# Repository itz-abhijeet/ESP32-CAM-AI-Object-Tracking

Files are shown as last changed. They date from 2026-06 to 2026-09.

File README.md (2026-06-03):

# ESP32-CAM AI Object Tracking Camera

This project is a prototype AI object-tracking camera built with an ESP32-CAM, a second ESP32, a PCA9685 servo driver, two MG995/MG996-style servos, a custom YOLO model, and 3D-printed mechanical parts.

The ESP32-CAM streams live video to my laptop over Wi-Fi. Python runs a trained YOLO model to detect my custom 3D-printed target object. Then Python sends movement commands to a second ESP32, which controls the pan and tilt servos through the PCA9685 servo driver.

The goal of this project was to connect AI object detection with real hardware movement and design my own mechanical parts instead of using a ready-made pan-tilt mount.

## Demo

Project photo:

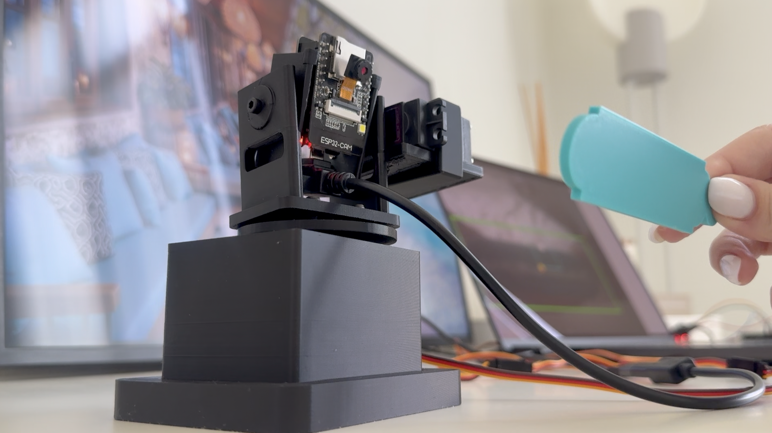
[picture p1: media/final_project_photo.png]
Final project photo


## How It Works

```text
ESP32-CAM
   ↓ Wi-Fi video stream
Laptop running Python + YOLO
   ↓ serial movement command
Second ESP32
   ↓ I2C
PCA9685 servo driver
   ↓
Pan and tilt servos
   ↓
Camera follows the object
```

## Hardware

* ESP32-CAM
* ESP32-WROOM-32 DevKit board
* PCA9685 16-channel servo driver
* 2 MG995/MG996-style servos
* External 5V power supply for the servos
* Jumper wires
* M3 screws
* Micro screws for the ESP32-CAM module
* 3D-printed camera mount parts

## Wiring

Basic wiring:

* ESP32 GPIO21 → PCA9685 SDA
* ESP32 GPIO22 → PCA9685 SCL
* ESP32 5V → PCA9685 VCC
* ESP32 GND → PCA9685 GND
* External 5V → PCA9685 V+
* External power GND → PCA9685 GND
* Pan servo → PCA9685 channel 0
* Tilt servo → PCA9685 channel 1

The PCA9685 uses I2C communication. SDA is the data line, and SCL is the clock line.

The servos are powered with external 5V power because servos need more current than the ESP32 should provide directly.

See wiring diagram:

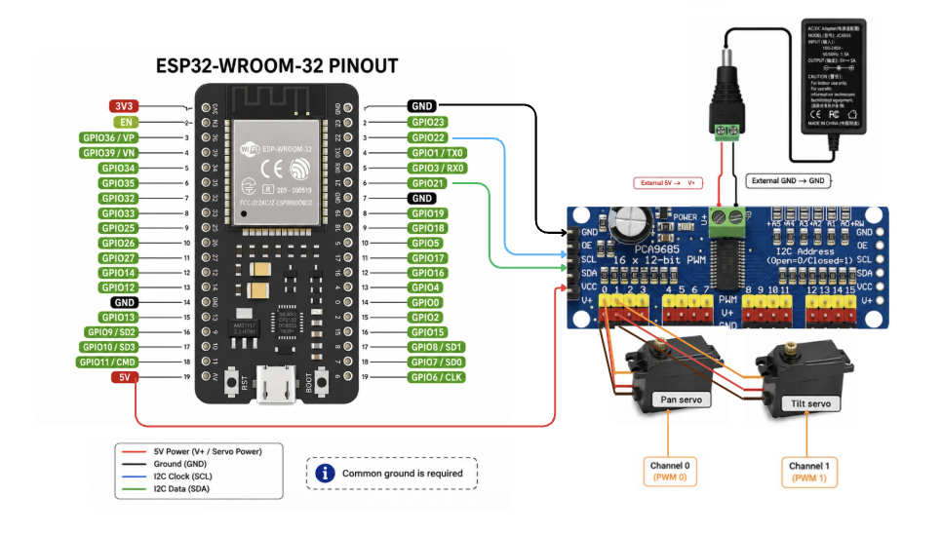
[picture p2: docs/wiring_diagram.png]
Wiring diagram


## 3D Printed Parts

The STL files are in the `stl/` folder.

The OpenSCAD source file is in the `openscad/` folder, so the design can be adjusted for different hardware.

This design was made for my specific prototype, so dimensions may need to be adjusted depending on your servo, camera board, screws, and printer tolerances.

## AI Model

I trained a custom YOLO model using my own images of a 3D-printed target object.

The trained model file is:

```text
models/best.pt
```

## Python Setup

Install the Python dependencies:

```bash
pip install -r requirements.txt
```

Update these values in `python/ai_tracking.py` for your own setup:

```python
MODEL_PATH = "../models/best.pt"
SERIAL_PORT = "YOUR_SERIAL_PORT"
CAMERA_URL = "http://YOUR_ESP32_CAM_IP:81/stream"
```

Run the main tracking script:

```bash
cd python
python3 ai_tracking.py
```

## Arduino Setup

Upload the ESP32-CAM streaming code to the ESP32-CAM:

```text
arduino/esp32_cam_stream/esp32_cam_stream.ino
```

Upload the servo controller code to the second ESP32:

```text
arduino/servo_controller/servo_controller.ino
```

Before uploading the ESP32-CAM code, replace the Wi-Fi placeholders with your own Wi-Fi name and password.

## Project Files

```text
python/
  capture_images.py
  prepare_dataset.py
  ai_tracking.py

arduino/
  esp32_cam_stream/
  servo_controller/

stl/
  3D-printable parts

openscad/
  editable OpenSCAD source

docs/
  wiring diagram and notes

models/
  trained YOLO model
```
## Testing

I also included a testing checklist for the full prototype behavior, including startup, tracking, lost-target behavior, servo movement, latency, edge limits, long-run stability, and thermal checks.

See: [Testing Checklist](docs/testing.md)

## Notes

This is still a prototype. The movement, wiring, 3D-printed parts, and code are still being improved.

For real-time tracking, a smaller and faster video stream worked better than a high-resolution stream with too much delay.

## License

This project is shared for learning and experimentation.

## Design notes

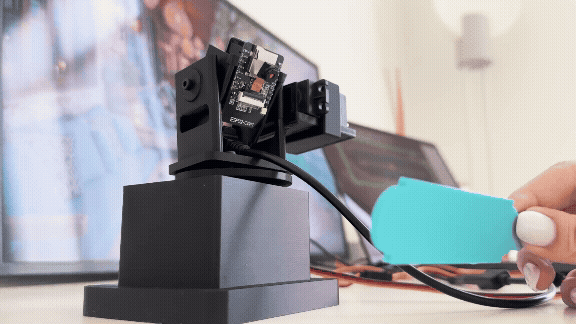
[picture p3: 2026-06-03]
media/demo.gif

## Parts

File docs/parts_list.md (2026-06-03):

# Setup Notes

- GPIO21 is used for SDA.
- GPIO22 is used for SCL.
- PCA9685 channel 0 controls the pan servo.
- PCA9685 channel 1 controls the tilt servo.
- Servos are powered with external 5V power.
- All grounds must be connected together.

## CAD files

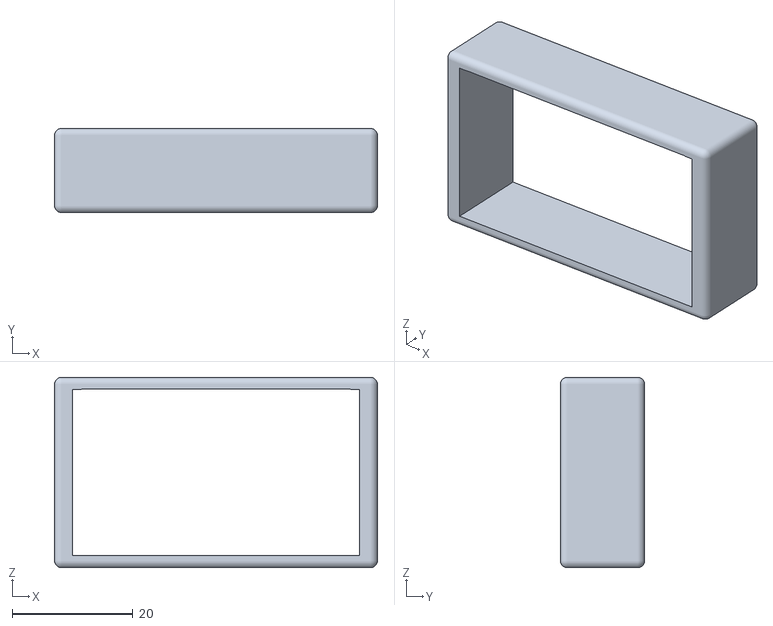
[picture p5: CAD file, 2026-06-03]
stl/servo_holder.stl
53.6 x 14.0 x 31.6

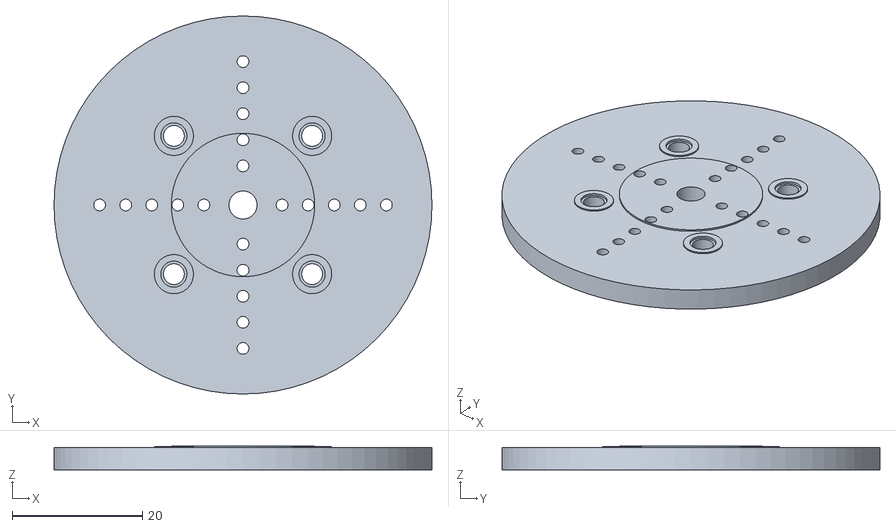
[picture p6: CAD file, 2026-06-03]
stl/horn.stl
58.0 x 58.0 x 3.65

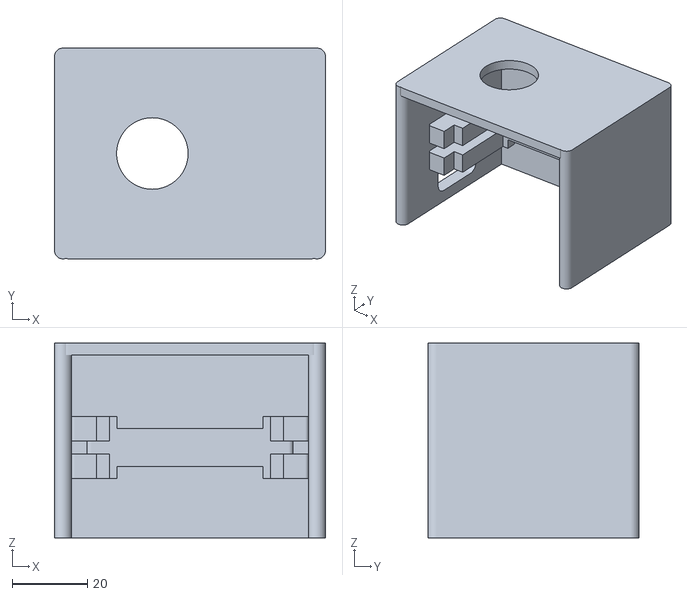
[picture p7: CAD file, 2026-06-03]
stl/pan_servo_cage.stl
72.0 x 56.0 x 51.7

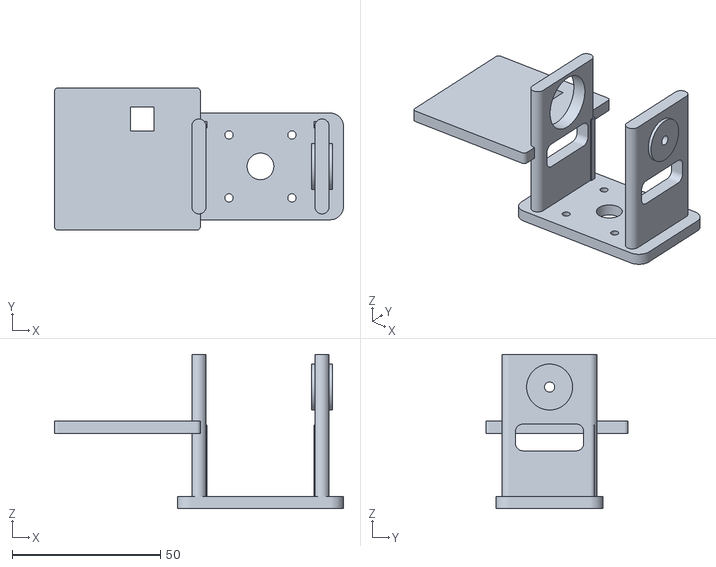
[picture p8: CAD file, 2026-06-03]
stl/tilt_yoke_base.stl
97.5 x 48.0 x 52.0

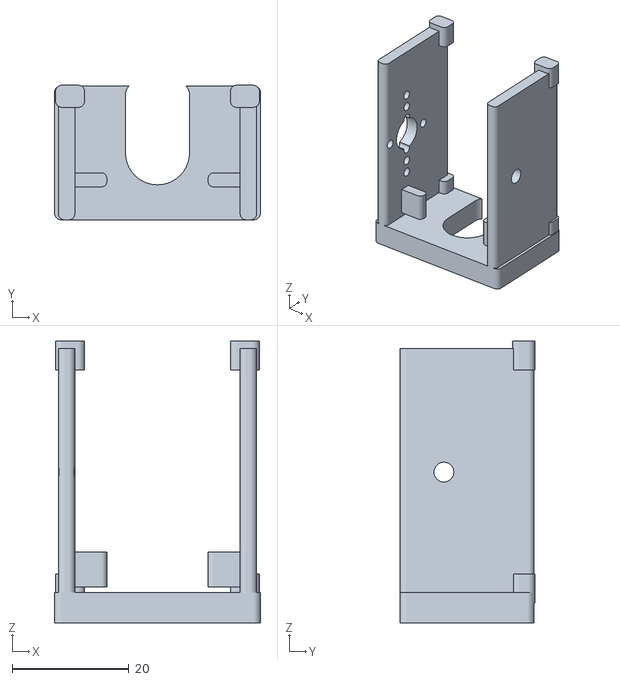
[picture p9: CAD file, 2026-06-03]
stl/camera_cradle.stl
35.4 x 23.1 x 48.4

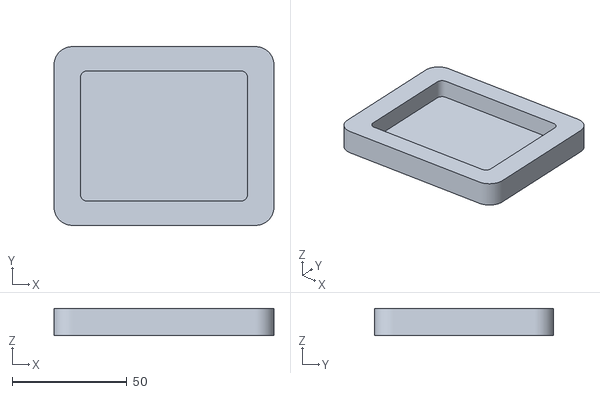
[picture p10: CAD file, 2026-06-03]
stl/base_plate.stl
96.0 x 78.0 x 12.0

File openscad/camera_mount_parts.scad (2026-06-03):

/*

  Main printable options:
    assembly
    base_plate
    pan_servo_cage
    pan_horn_disk
    tilt_yoke_base
    camera_cradle
    servo_holder
*/

$fn = 72;

PART = "assembly";

servo_holder_file = "../stl/servo_holder.stl";


m25_clear = 2.8;
m3_clear = 3.4;

cam_w = 27.0;
cam_h = 40.0;
cam_t = 19.0;

cam_clear_w = cam_w + 1.4;
cam_clear_h = cam_h + 1.4;
cam_clear_t = cam_t + 1.8;

base_plate_x = 96;
base_plate_y = 78;
base_plate_h = 4.0;
base_plate_r = 8.0;

cage_h = 39;
servo_center_z = 15.8;
ear_shelf_x = 9.5;
ear_shelf_y = 18.0;
ear_shelf_h = 3.2;

pan_disk_d = 43;
pan_disk_h = 5.0;
pan_screw_circle = 30;

yoke_base_h = 5;

yoke_inner_w = 36;
yoke_arm_t = 5.5;
yoke_arm_h = 49;
yoke_axis_z = 34;

left_arm_x = -(yoke_inner_w/2 + yoke_arm_t/2);
right_arm_x =  (yoke_inner_w/2 + yoke_arm_t/2);


cradle_w = cam_clear_w + 5.0;
cradle_t = cam_clear_t + 2.2;

module rounded_box(size=[10,10,10], r=2, center=false) {
    x=size[0]; y=size[1]; z=size[2];
    rr = min(r, min(x,y)/2 - 0.01);
    translate(center ? [-x/2,-y/2,-z/2] : [0,0,0])
        hull() {
            for (ix=[rr, x-rr])
                for (iy=[rr, y-rr])
                    translate([ix,iy,0]) cylinder(h=z, r=rr);
        }
}

module cyl_x(d,l) { rotate([0,90,0]) cylinder(d=d, h=l, center=true); }

module cyl_y(d,l) { rotate([90,0,0]) cylinder(d=d, h=l, center=true); }

module rounded_panel_y(w,h,depth,r) {
    union() {
        cube([max(0.01,w-2*r), depth, h], center=true);
        cube([w, depth, max(0.01,h-2*r)], center=true);
        for (sx=[-1,1])
            for (sz=[-1,1])
                translate([sx*(w/2-r),0,sz*(h/2-r)]) cyl_y(2*r, depth);
    }
}

module rounded_panel_x(w_y,h_z,depth_x,r) {
    union() {
        cube([depth_x, max(0.01,w_y-2*r), h_z], center=true);
        cube([depth_x, w_y, max(0.01,h_z-2*r)], center=true);
        for (sy=[-1,1])
            for (sz=[-1,1])
                translate([0,sy*(w_y/2-r),sz*(h_z/2-r)]) cyl_x(2*r, depth_x);
    }
}

module screw_circle_z(radius=15, d=2.8, h=8) {
    for (a=[45,135,225,315])
        rotate([0,0,a])
            translate([radius,0,0])
                cylinder(d=d, h=h, center=true);
}

module screw_square_x(y=10,z=10,d=2.4,depth=8) {
    for (sy=[-1,1])
        for (sz=[-1,1])
            translate([0, sy*y, sz*z]) cyl_x(d, depth);
}

module screw_square_y(x=16,z=22,d=2.4,depth=8) {
    for (sx=[-1,1])
        for (sz=[-1,1])
            translate([sx*x, 0, sz*z]) cyl_y(d, depth);
}

module bottom_base_plate_v1() {

    plate_h = 12.0;

    pan_cage_x = 72.0;
    pan_cage_y = 56.0;

    pan_cage_clearance = 0.9;

    pocket_x = pan_cage_x + pan_cage_clearance;
    pocket_y = pan_cage_y + pan_cage_clearance;

    pocket_depth = 9.0;

    bottom_floor = plate_h - pocket_depth;

    pocket_r = 3.0;

    pocket_shift_x = 0.0;
    pocket_shift_y = 0.0;

    plate_top_z = plate_h / 2;

    pocket_center_z = plate_top_z - pocket_depth / 2 + 0.01;

    difference() {
        rounded_box(
            [base_plate_x, base_plate_y, plate_h],
            r=base_plate_r,
            center=true
        );

        translate([
            pocket_shift_x,
            pocket_shift_y,
            pocket_center_z
        ])
            rounded_box(
                [pocket_x, pocket_y, pocket_depth + 0.08],
                r=pocket_r,
                center=true
            );
    }
}

module pan_servo_open_cage_v1() {

    mg_body_x = 40.0;
    mg_body_y = 20.0;
    mg_body_z = 40.5;

    mg_body_clear_x = mg_body_x + 2.8;
    mg_body_clear_y = mg_body_y + 2.6;
    mg_body_clear_z = mg_body_z + 2.5;

    mg_shaft_from_near_edge = 10;
    mg_boss_x_offset = -mg_body_x/2 + mg_shaft_from_near_edge;

    mg_boss_clear_d   = 19.0;
    mg_spline_clear_d = 10.5;

    mg_side_wall = 4.5;
    mg_back_wall = 4.5;
    mg_roof_h = 3.2;

    mg_bottom_gap = 2.5;

    mg_top_air_gap = 3.0;

    mg_servo_center_z = mg_bottom_gap + mg_body_clear_z/2;

    mg_cage_x = 72.0;
    mg_cage_y = 56.0;
    mg_cage_h = mg_bottom_gap + mg_body_clear_z + mg_top_air_gap + mg_roof_h;

    mg_mount_x = 29.0;
    mg_mount_y = 21.0;
    mg_mount_hole_d = 3.4;

    front_open_y = mg_cage_y/2 + 8.0;

    left_inner_x  = -mg_cage_x/2 + mg_side_wall;
    right_inner_x =  mg_cage_x/2 - mg_side_wall;

    wire_side = -1;

    wire_exit_y = 0.0;
    wire_exit_z = 10.0;
    wire_exit_w = 20.0;
    wire_exit_h = 12.0;

    body_half_x = mg_body_clear_x/2;
    guide_protrude = (mg_cage_x/2 - mg_side_wall) - body_half_x + 2.0;
    guide_y = mg_body_clear_y + 8.0;
    guide_h = 6.5;

    guide_z_low  = mg_servo_center_z - 5.0;
    guide_z_high = mg_servo_center_z + 5;

    rear_stop_inner_y = mg_body_clear_y/2;
    rear_stop_outer_y = mg_cage_y/2 - mg_back_wall;
    rear_stop_y_len = rear_stop_outer_y - rear_stop_inner_y;
    rear_stop_y_center = rear_stop_inner_y + rear_stop_y_len/2;
    rear_stop_h = 10.0;

    difference() {
        union() {
            translate([-mg_cage_x/2 + mg_side_wall/2, 0, mg_cage_h/2])
                rounded_box(
                    [mg_side_wall, mg_cage_y, mg_cage_h],
                    r=3,
                    center=true
                );

            translate([mg_cage_x/2 - mg_side_wall/2, 0, mg_cage_h/2])
                rounded_box(
                    [mg_side_wall, mg_cage_y, mg_cage_h],
                    r=3,
                    center=true
                );

            translate([0, mg_cage_y/2 - mg_back_wall/2, mg_cage_h/2])
                rounded_box(
                    [mg_cage_x, mg_back_wall, mg_cage_h],
                    r=3,
                    center=true
                );

            translate([0, 0, mg_cage_h - mg_roof_h/2])
                rounded_box(
                    [mg_cage_x, mg_cage_y, mg_roof_h],
                    r=4,
                    center=true
                );

            for (sx=[-1,1])
                for (gz=[guide_z_low, guide_z_high])
                    translate([
                        sx * (mg_cage_x/2 - mg_side_wall - guide_protrude/2),
                        0,
                        gz
                    ])
                        rounded_box(
                            [guide_protrude, guide_y, guide_h],
                            r=0.9,
                            center=true
                        );

            translate([0, rear_stop_y_center, mg_servo_center_z])
                rounded_box(
                    [mg_body_clear_x + 12.0, rear_stop_y_len, rear_stop_h],
                    r=1.2,
                    center=true
                );
        }

        translate([0, 0, mg_servo_center_z])
            cube(
                [mg_body_clear_x, mg_body_clear_y, mg_body_clear_z],
                center=true
            );

        translate([0, -mg_cage_y/2, mg_servo_center_z])
            cube(
                [mg_body_clear_x + 7.0, front_open_y, mg_body_clear_z + 4.0],
                center=true
            );

        translate([mg_boss_x_offset, 0, mg_cage_h - mg_roof_h/2])
            cylinder(
                d=mg_boss_clear_d,
                h=mg_roof_h + 5.0,
                center=true
            );

        translate([mg_boss_x_offset, 0, mg_cage_h])
            cylinder(
                d=mg_spline_clear_d,
                h=16.0,
                center=true
            );

        for (sx=[-1,1])
            for (sy=[-1,1])
                translate([sx*mg_mount_x, sy*mg_mount_y, 3])
                    cylinder(
                        d=mg_mount_hole_d,
                        h=14,
                        center=true
                    );

        translate([
            wire_side * mg_cage_x/2,
            wire_exit_y,
            wire_exit_z
        ])
            rounded_panel_x(
                wire_exit_w,
                wire_exit_h,
                mg_side_wall + 10,
                3
            );
    }
}

module pan_horn_adapter_disk_v1() {

    local_eps = 0.02;

    disk_h = 3.4;

    adapter_disk_d = max(pan_disk_d, 58.0);

    mg_horn_recess_depth = 1.0;

    mg_horn_center_d = 21.5;

    mg_horn_arm_w = 7.8;
    mg_horn_arm_len = 44.0;

    mg_center_access_d = 4.3;

    mg_horn_hole_d_horizontal = 1.8;
    mg_horn_hole_d_vertical   = 1.8;

    mg_horn_hole_positions = [6, 10, 14, 18, 22];

    outer_screw_d = 3.2;

    neck_counterbore_d = 4.0;
    neck_counterbore_depth = 0.35;

    difference() {
        union() {
            cylinder(
                d=adapter_disk_d,
                h=disk_h,
                center=true
            );

            translate([0, 0, disk_h/2])
                cylinder(
                    d=22.0,
                    h=0.5,
                    center=true
                );
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

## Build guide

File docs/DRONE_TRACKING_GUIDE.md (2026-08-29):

# Optical Drone Detection & Tracking Setup Guide

This guide explains how to connect and configure this project hardware and software specifically for optical drone (UAV) detection and tracking using computer vision and standard pan-tilt mounts.

---

## 1. System Architecture

```text
[ ESP32-CAM ] 
      │ (Wi-Fi MJPEG Stream)
      ▼
[ Laptop / PC ] ── (Runs YOLO Detection + PID Tracking)
      │ (USB Serial: Movement Commands)
      ▼
[ ESP32 Controller ] 
      │ (I2C)
      ▼
[ PCA9685 Driver ] ── (PWM) ──> [ Pan / Tilt Servos ]
```

---

## 2. Hardware Connections

### Wiring Diagram

1. **Second ESP32 to PCA9685 Driver (I2C Control):**
   * `ESP32 GPIO 21 (SDA)` → `PCA9685 SDA`
   * `ESP32 GPIO 22 (SCL)` → `PCA9685 SCL`
   * `ESP32 5V / VIN` → `PCA9685 VCC` (Logic Power)
   * `ESP32 GND` → `PCA9685 GND`

2. **PCA9685 to Servos & External Power:**
   * **Pan Servo:** Plug into **Channel 0** on the PCA9685.
   * **Tilt Servo:** Plug into **Channel 1** on the PCA9685.
   * **External 5V Power Supply:** Connect to the `V+` and `GND` screw terminals on the PCA9685.

> **Important:** Always connect the ground (`GND`) of the external power supply and the ESP32 together to maintain a common ground reference. Never draw servo operating current directly from the ESP32 board pins.

---

## 3. Firmware Flashing

### A. ESP32-CAM (Video Streaming)
1. Open `arduino/esp32_cam_stream/esp32_cam_stream.ino` in the Arduino IDE.
2. Update your local Wi-Fi details:
   ```cpp
   const char* ssid = "YOUR_WIFI_SSID";
   const char* password = "YOUR_WIFI_PASSWORD";
   ```
3. Set the board to **AI Thinker ESP32-CAM** and upload.
4. Open the Serial Monitor (115200 baud) to obtain the device's IP address (e.g., `http://192.168.1.50:81/stream`).

### B. Second ESP32 (Pan/Tilt Motion Controller)
1. Open `arduino/servo_controller/servo_controller.ino` in the Arduino IDE.
2. Select your board (e.g., **ESP32 Dev Module**) and target COM port.
3. Upload the firmware. Leave the ESP32 connected to the PC via USB.

---

## 4. Software Configuration for Drone Detection

### Model Selection
Standard YOLO models (such as YOLOv8) can detect commercial drones or aerial objects using custom datasets or classes such as `airplane` or custom-trained drone weights (`.pt`).

### Updating `python/ai_tracking.py`
Edit the configuration variables in `python/ai_tracking.py`:

```python
# Path to your YOLO model trained on drone imagery
MODEL_PATH = "yolov8n.pt"  # Or your custom drone detection model: "models/drone_model.pt"

# Serial port connected to the Second ESP32
SERIAL_PORT = "COM3"  # Adjust based on your Device Manager / COM port

# ESP32-CAM stream URL obtained from Serial Monitor
CAMERA_URL = "http://192.168.1.50:81/stream"
```

---

## 5. Running the Tracker

1. Power on the servos and ESP32-CAM.
2. Run the main tracking script:
   ```bash
   cd python
   python ai_tracking.py
   ```
3. The optical tracker will stream the video feed, detect the aerial target, compute position offsets from the frame center, and send real-time pan/tilt correction commands to maintain visual lock.

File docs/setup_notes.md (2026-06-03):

# Parts List

- ESP32-CAM
- ESP32-WROOM-32 DevKit board
- PCA9685 16-channel servo driver
- 2 servos
- External 5V power supply
- Jumper wires
- M3 screws
- Micro screws for ESP32-CAM module
- 3D-printed parts

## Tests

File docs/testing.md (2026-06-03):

# Testing Checklist

This checklist was used to test the ESP32-CAM AI object-tracking prototype as a full system.

The full system flow is:

```text
ESP32-CAM video stream
→ Python + YOLO detection
→ object center calculation
→ serial movement command
→ second ESP32
→ PCA9685 servo driver
→ pan/tilt servo movement
→ camera follows the target
```

This project is still a prototype, so the checklist focuses on behavior, stability, safety, and repeatability.

---

## 1. Startup Test

**Goal:** Make sure the system starts cleanly.

**Steps:**

1. Power the ESP32-CAM.
2. Power the second ESP32 and servo driver.
3. Start the Python tracking script.
4. Check the terminal, OpenCV window, and physical camera movement.

**Expected result:**

* YOLO model loads successfully.
* Serial port opens.
* ESP32-CAM stream opens.
* OpenCV window appears.
* Camera receives the center command.
* Servos move to the center position smoothly.
* No sudden movement or servo buzzing.

---

## 2. Center Command Test

**Goal:** Make sure the `C` command centers the camera correctly.

**Steps:**

1. Start tracking.
2. Let the camera follow the target.
3. Press `c` in the OpenCV window.

**Expected result:**

* Camera returns to center smoothly.
* Old movement commands are cleared.
* Tracking resumes normally after centering.
* Camera does not jump back to an old target position.

---

## 3. Quit Behavior Test

**Goal:** Make sure the program exits cleanly.

**Steps:**

1. Start tracking.
2. Let the camera move.
3. Press `q`.

**Expected result:**

* Camera sends a center command before exit.
* OpenCV window closes.
* Serial port closes.
* Python process exits.
* The next launch works without a “port busy” error.

---

## 4. No Target Test

**Goal:** Make sure the camera stays stable when the target is not visible.

**Steps:**

1. Remove the target object from the camera view.
2. Watch the OpenCV window and physical camera.

**Expected result:**

* Camera stops moving.
* No random searching behavior.
* No tracking of the background.
* OpenCV window shows “No target detected.”
* Terminal shows “No target.”

---

## 5. Lost Target While Moving Test

**Goal:** Make sure the camera stops when the target disappears during movement.

**Steps:**

1. Put the target object on one side of the frame.
2. Let the camera begin moving toward it.
3. Quickly remove the object from the frame.

**Expected result:**

* Camera stops shortly after the target disappears.
* Camera does not continue moving toward the old target position.
* No delayed movement or runaway behavior.

---

## 6. Target Reacquisition Test

**Goal:** Make sure tracking restarts correctly when the object returns.

**Steps:**

1. Remove the target for 2–3 seconds.
2. Put the target back into the frame.

**Expected result:**

* System may briefly show `LOCKING`.
* Tracking resumes after stable detection.
* Camera does not jump suddenly to an old position.
* Camera follows the target again normally.

---

## 7. Pan Direction Test

**Goal:** Verify left/right movement direction.

**Steps:**

1. Put the target near the center.
2. Move the target slowly to the right.
3. Move the target slowly to the left.

**Expected result:**

* Target moves right → camera pans right.
* Target moves left → camera pans left.
* Camera moves toward the target, not away from it.

---

## 8. Tilt Direction Test

**Goal:** Verify up/down movement direction.

**Steps:**

1. Put the target near the center.
2. Move the target upward.
3. Move the target downward.

**Expected result:**

* Target moves up → camera tilts up.
* Target moves down → camera tilts down.
* Tilt axis does not move in the opposite direction.

---

## 9. Hold Zone Test

**Goal:** Make sure the camera does not twitch when the object is already near the center.

**Steps:**

1. Put the object close to the center of the frame.
2. Move it slightly inside the hold-zone rectangle.

**Expected result:**

* Camera stays still.
* Status shows `HOLD`.
* Movement commands stay near `D=(0,0)`.
* No small left/right or up/down twitching.

---

## 10. Smooth Tracking Test

**Goal:** Check normal smooth tracking behavior.

**Steps:**

1. Move the target slowly from left to right.
2. Move it from right to left.
3. Move it up and down.

**Expected result:**

* Camera follows smoothly.
* Movement does not look shaky.
* Object stays near the center.
* No repeated stop-go-stop-go behavior.

---

## 11. Fast Movement Test

**Goal:** Check how the system reacts when the object moves quickly.

**Steps:**

1. Start with the target in the center.
2. Move it quickly to the side.
3. Move it quickly up or down.

**Expected result:**

* Camera reacts without going out of control.
* Camera does not overshoot too much.
* Movement settles after the object stops.
* No continuous oscillation.

---

## 12. False Positive Test

**Goal:** Make sure the camera does not follow random objects.

**Steps:**

1. Remove the target object.
2. Place similar-looking objects or hands in the frame.
3. Change the background or lighting.

**Expected result:**

* YOLO does not confidently track the wrong object.
* Camera does not aggressively follow the background.
* If false detections happen, they should be limited and not cause unstable movement.

---

## 13. Latency Test

**Goal:** Check if the camera is reacting to recent frames instead of old buffered frames.

**Steps:**

1. Move the target quickly in front of the camera.
2. Watch the OpenCV window.
3. Watch the physical servo response.

**Expected result:**

* OpenCV window shows the recent target position.
* Camera does not follow where the target was one second ago.
* Tracking delay is acceptable for a prototype.

---

## 14. Edge Limit Test

**Goal:** Make sure servos stay within safe physical limits.

**Steps:**

1. Move the target far left and far right.
2. Move the target high and low.
3. Watch the servo and 3D-printed parts.

**Expected result:**

* Camera does not hit the plastic frame.
* Servo horn does not push against the mount.
* Camera cable does not get pulled.
* No buzzing at servo limits.

---

## 15. Arduino Timeout Test

**Goal:** Make sure the servo controller stops safely if Python stops sending commands.

**Steps:**

1. Start tracking.
2. Let the camera move.
3. Stop or crash the Python script.

**Expected result:**

* Arduino stops updating movement after command timeout.
* Camera does not keep moving forever.
* Servo controller does not freeze.
* System can be restarted normally.

---

## 16. Command Protocol Test

**Goal:** Verify Python-to-Arduino serial commands.

**Command format:**

```text
C
D,panDelta,tiltDelta
```

**Expected result:**

* `C` centers the camera.
* `D,x,y` moves pan and tilt.
* `D,0,0` stops movement.
* Commands do not look chaotic when the target is near the center.

---

## 17. Long Run Test

**Goal:** Check stability over time.

**Steps:**

1. Run the project for 15–30 minutes.
2. Move the target occasionally.
3. Remove and return the target.
4. Press `c` occasionally to center.

**Expected result:**

* Python does not crash.
* Camera stream does not freeze.
* Serial connection stays active.
* Servos do not overheat.
* Tracking behavior stays consistent.

---

## 18. Thermal Test

**Goal:** Check if the electronics and servos stay within a safe temperature range.

**Steps:**
After a longer run, check:

* ESP32-CAM
* second ESP32
* PCA9685
* pan servo
* tilt servo

**Expected result:**

* Warm is expected.
* Very hot or too hot to touch is not good.
* If a servo is very hot, check mechanical friction, servo limits, weight balance, and power supply.

---

## 19. Repeatability Test

**Goal:** Make sure the project works consistently across multiple launches.

**Steps:**
Repeat 5 times:

1. Start Python.
2. Center the camera.
3. Track left/right.
4. Track up/down.
5. Remove target.
6. Return target.
7. Press `c`.
8. Press `q`.

**Expected result:**

* Behavior is consistent across launches.
* Serial port is released correctly.
* Camera centers correctly every time.
* Tracking does not become worse after restart.

---

## 20. Demo Quality Test

**Goal:** Check if the project is understandable in a short demo video.

**Expected result:**

* Within the first few seconds, it is clear that the camera follows the object.
* Movement looks smooth enough for a prototype.
* The object is visible.
* The camera does not look confused.
* The wiring and mechanical parts look intentional.
* The demo can be understood without a long explanation.

---

## Notes

This is a working prototype, not a commercial product. The tracking quality depends on:

* lighting
* ESP32-CAM stream quality
* camera latency
* servo power
* mechanical alignment
* target visibility
* YOLO model quality
* tuning values in the Python and Arduino code

Some values may need to be adjusted for different hardware or 3D-printed parts.

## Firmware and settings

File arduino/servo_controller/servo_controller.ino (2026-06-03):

#include <Wire.h>
#include <math.h>

#define PCA9685_ADDR 0x40

#define PAN_CH 0
#define TILT_CH 1

/*
  Servo controller for ESP32-CAM AI object tracking project

  Hardware:
  - Second ESP32-WROOM-32 DevKit
  - PCA9685 servo driver
  - Pan servo on PCA9685 channel 0
  - Tilt servo on PCA9685 channel 1
  - I2C: GPIO21 = SDA, GPIO22 = SCL

  Commands from Python:
  - C = center servos
  - D,panDelta,tiltDelta = move pan/tilt servos
*/

// SERVO CENTER

int panCenter = 300;
int tiltCenter = 410;

float panPos = panCenter;
float tiltPos = tiltCenter;

float targetPan = panCenter;
float targetTilt = tiltCenter;


// CENTER ANIMATION STATE

bool centeringMode = false;

float centerStartPan = 0;
float centerStartTilt = 0;

unsigned long centerStartTime = 0;

// Higher = slower
unsigned long centerDurationMs = 1150;

int centerWriteDeadband = 1;

// SERVO LIMITS

// PAN = left/right
int panMin = 180;
int panMax = 430;

// TILT = up/down
int tiltMin = 230;
int tiltMax = 470;

int PAN_DIR = 1;
int TILT_DIR = 1;

// TRACKING SETTINGS

unsigned long servoUpdateMs = 6;
unsigned long lastServoUpdate = 0;

int panMaxTargetLead = 45;
int tiltMaxTargetLead = 40;

unsigned long commandTimeoutMs = 500;
unsigned long lastCommandTime = 0;

float arriveThreshold = 2;

// PAN tuning
float panMinStep = 0.8;
float panMaxStep = 6.2;
float panGain = 0.15;

// TILT tuning
float tiltMinStep = 0.5;
float tiltMaxStep = 4.0;
float tiltGain = 0.09;

int tinyPanDeltaIgnore = 1;
int tinyTiltDeltaIgnore = 0;

int panWriteDeadband = 2;
int tiltWriteDeadband = 2;

int lastPanPWM = -9999;
int lastTiltPWM = -9999;

// SERIAL LINE BUFFER

char serialBuffer[48];
int serialIndex = 0;

// PCA9685 LOW LEVEL FUNCTIONS

void writeRegister(byte reg, byte value) {
  Wire.beginTransmission(PCA9685_ADDR);
  Wire.write(reg);
  Wire.write(value);
  Wire.endTransmission();
}

void setPWM(byte channel, int on, int off) {
  Wire.beginTransmission(PCA9685_ADDR);
  Wire.write(0x06 + 4 * channel);

  Wire.write(on & 0xFF);
  Wire.write(on >> 8);

  Wire.write(off & 0xFF);
  Wire.write(off >> 8);

  Wire.endTransmission();
}

void setupPCA9685() {
  writeRegister(0x00, 0x10);  // sleep
  writeRegister(0xFE, 121);   // about 50 Hz for servos
  writeRegister(0x00, 0x00);  // wake
  delay(10);
  writeRegister(0x00, 0xA1);  // auto-increment
}

void moveServo(byte ch, int pwm) {
  setPWM(ch, 0, pwm);
}

void moveServoIfChanged(byte ch, int pwm, int &lastPWM, int deadband) {
  if (lastPWM == -9999 || abs(pwm - lastPWM) >= deadband) {
    moveServo(ch, pwm);
    lastPWM = pwm;
  }
}

// HELPER FUNCTIONS

float absFloat(float value) {
  if (value < 0) return -value;
  return value;
}

float clampFloat(float value, float minVal, float maxVal) {
  if (value < minVal) return minVal;
  if (value > maxVal) return maxVal;
  return value;
}

float easeInOutCos(float t) {
  t = clampFloat(t, 0.0, 1.0);
  return 0.5 - 0.5 * cos(t * 3.14159265);
}

float adaptiveStep(float diff, float minStep, float maxStep, float gain) {
  float absDiff = absFloat(diff);

  if (absDiff <= arriveThreshold) {
    return absDiff;
  }

  float step = minStep + absDiff * gain;

  if (step > maxStep) step = maxStep;
  if (step < minStep) step = minStep;

  return step;
}

void freezeTargetsToCurrent() {
  centeringMode = false;
  targetPan = panPos;
  targetTilt = tiltPos;
}

void centerServos() {
  centerStartPan = panPos;
  centerStartTilt = tiltPos;
  centerStartTime = millis();

  targetPan = panCenter;
  targetTilt = tiltCenter;

  centeringMode = true;
}

void applyTargetLeadLimit() {
  targetPan = clampFloat(
    targetPan,
    panPos - panMaxTargetLead,
    panPos + panMaxTargetLead
  );

  targetTilt = clampFloat(
    targetTilt,
    tiltPos - tiltMaxTargetLead,
    tiltPos + tiltMaxTargetLead
  );

  targetPan = clampFloat(targetPan, panMin, panMax);
  targetTilt = clampFloat(targetTilt, tiltMin, tiltMax);
}

// SERVO UPDATE

void updateSmoothServos() {
  unsigned long now = millis();

  if (now - lastServoUpdate < servoUpdateMs) {
    return;
  }

  lastServoUpdate = now;

  if (centeringMode) {
    float t = (now - centerStartTime) / (float)centerDurationMs;

    if (t >= 1.0) {
      panPos = panCenter;
      tiltPos = tiltCenter;

      targetPan = panCenter;
      targetTilt = tiltCenter;

      centeringMode = false;
    } else {
      float e = easeInOutCos(t);

      panPos = centerStartPan + (panCenter - centerStartPan) * e;
      tiltPos = centerStartTilt + (tiltCenter - centerStartTilt) * e;
    }

    panPos = clampFloat(panPos, panMin, panMax);
    tiltPos = clampFloat(tiltPos, tiltMin, tiltMax);

    int panPWM = (int)round(panPos);
    int tiltPWM = (int)round(tiltPos);

    moveServoIfChanged(PAN_CH, panPWM, lastPanPWM, centerWriteDeadband);
    moveServoIfChanged(TILT_CH, tiltPWM, lastTiltPWM, centerWriteDeadband);

    return;
  }

  if (now - lastCommandTime > commandTimeoutMs) {
    freezeTargetsToCurrent();
  }

  applyTargetLeadLimit();

  float panDiff = targetPan - panPos;
  float tiltDiff = targetTilt - tiltPos;

  // PAN / LEFT-RIGHT
  if (absFloat(panDiff) <= arriveThreshold) {
    panPos = targetPan;
  } else {
    float step = adaptiveStep(
      panDiff,
      panMinStep,
      panMaxStep,
      panGain
    );

    if (panDiff > 0) {
      panPos += step;
      if (panPos > targetPan) panPos = targetPan;
    } else {
      panPos -= step;
      if (panPos < targetPan) panPos = targetPan;
    }
  }

  // TILT / UP-DOWN
  if (absFloat(tiltDiff) <= arriveThreshold) {
    tiltPos = targetTilt;
  } else {
    float step = adaptiveStep(
      tiltDiff,
      tiltMinStep,
      tiltMaxStep,
      tiltGain
    );

    if (tiltDiff > 0) {
      tiltPos += step;
      if (tiltPos > targetTilt) tiltPos = targetTilt;
    } else {
      tiltPos -= step;
      if (tiltPos < targetTilt) tiltPos = targetTilt;
    }
  }

  panPos = clampFloat(panPos, panMin, panMax);
  tiltPos = clampFloat(tiltPos, tiltMin, tiltMax);

  int panPWM = (int)round(panPos);
  int tiltPWM = (int)round(tiltPos);

  moveServoIfChanged(PAN_CH, panPWM, lastPanPWM, panWriteDeadband);
  moveServoIfChanged(TILT_CH, tiltPWM, lastTiltPWM, tiltWriteDeadband);
}

// COMMAND HANDLING

void handleCommand(char *cmd) {
  if (cmd[0] == 'C' || cmd[0] == 'c') {
    centerServos();
    lastCommandTime = millis();
    Serial.println("CENTER");
    return;
  }

  int panDelta = 0;
  int tiltDelta = 0;

  if (sscanf(cmd, "D,%d,%d", &panDelta, &tiltDelta) == 2 ||
      sscanf(cmd, "d,%d,%d", &panDelta, &tiltDelta) == 2) {

    lastCommandTime = millis();


    centeringMode = false;

    if (panDelta == 0 && tiltDelta == 0) {
      freezeTargetsToCurrent();
      return;
    }


    if (abs(panDelta) <= tinyPanDeltaIgnore) {
      panDelta = 0;
    }


    if (abs(tiltDelta) <= tinyTiltDeltaIgnore) {
      tiltDelta = 0;
    }

    if (panDelta == 0 && tiltDelta == 0) {
      return;
    }

    panDelta *= PAN_DIR;
    tiltDelta *= TILT_DIR;

    targetPan += panDelta;
    targetTilt += tiltDelta;

    targetPan = clampFloat(targetPan, panMin, panMax);
    targetTilt = clampFloat(targetTilt, tiltMin, tiltMax);

    applyTargetLeadLimit();
  }
}

void readSerialNonBlocking() {
  while (Serial.available()) {
    char c = Serial.read();

    if (c == '\n' || c == '\r') {
      if (serialIndex > 0) {
        serialBuffer[serialIndex] = '\0';
        handleCommand(serialBuffer);
        serialIndex = 0;
      }
    } else {
      if (serialIndex < sizeof(serialBuffer) - 1) {
        serialBuffer[serialIndex++] = c;
      } else {
        serialIndex = 0;
      }
    }
  }
}


// SETUP / LOOP


void setup() {
  Serial.begin(115200);

  Wire.begin(21, 22);
  Wire.setClock(400000);

  setupPCA9685();

  int panPWM = (int)round(panPos);
  int tiltPWM = (int)round(tiltPos);

  moveServo(PAN_CH, panPWM);
  moveServo(TILT_CH, tiltPWM);

  lastPanPWM = panPWM;
  lastTiltPWM = tiltPWM;

  lastCommandTime = millis();

  Serial.println("READY PAN FAST / SMOOTH CENTER");
}

void loop() {
  readSerialNonBlocking();
  updateSmoothServos();
}

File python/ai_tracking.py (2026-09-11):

import os
import cv2
import serial
import time
import threading
import math
import socket
import urllib.request
import numpy as np
from pathlib import Path
from dotenv import load_dotenv
from ultralytics import YOLO

# Optional: push live data to AstraNex UI server (ui_server.py)
try:
    from tracking_bridge import push_state as _push_state, push_frame as _push_frame
    UI_ENABLED = True
except ImportError:
    UI_ENABLED = False
    def _push_state(*a, **kw): pass
    def _push_frame(*a, **kw): pass

# Load .env from python directory or project root
load_dotenv(dotenv_path=Path(__file__).resolve().parent / ".env")
load_dotenv(dotenv_path=Path(__file__).resolve().parent.parent / ".env")

# SETTINGS

# Path to the trained YOLO model
_raw_model_path = os.getenv("MODEL_PATH", "../models/bestmain.pt")
_model_path_obj = Path(_raw_model_path)
if not _model_path_obj.is_absolute() and not _model_path_obj.exists():
    if (Path(__file__).resolve().parent / _raw_model_path).exists():
        _model_path_obj = Path(__file__).resolve().parent / _raw_model_path
    elif (Path(__file__).resolve().parent.parent / _raw_model_path).exists():
        _model_path_obj = Path(__file__).resolve().parent.parent / _raw_model_path
    elif (Path(__file__).resolve().parent.parent / "models" / Path(_raw_model_path).name).exists():
        _model_path_obj = Path(__file__).resolve().parent.parent / "models" / Path(_raw_model_path).name
MODEL_PATH = str(_model_path_obj)

# Example on macOS: "/dev/cu.usbserial-XXXX"
# Example on Windows: "COM3"
# Example on Linux / Docker: "/dev/ttyUSB0"
SERIAL_PORT = os.getenv("SERIAL_PORT", "YOUR_SERIAL_PORT")

# Replace with your ESP32-CAM stream URL
CAMERA_URL = os.getenv("CAMERA_URL", "http://YOUR_ESP32_CAM_IP:81/stream")

# Set HEADLESS=true in Docker or server environments without a display
HEADLESS = os.getenv("HEADLESS", "false").lower() in ("true", "1", "yes")

PAN_SIGN = int(os.getenv("PAN_SIGN", "-1"))
TILT_SIGN = int(os.getenv("TILT_SIGN", "-1"))

# Recognition settings
IMG_SIZE = 320
CONFIDENCE = float(os.getenv("CONFIDENCE", "0.35"))
TARGET_CLASS = os.getenv("TARGET_CLASS", "person")

FRAME_W = 320
FRAME_H = 240

# MOVEMENT SETTINGS

# PAN / LEFT-RIGHT

HOLD_X = 22
FAR_X = 80

KP_PAN_NEAR = 0.10
KP_PAN_FAR = 0.22

MAX_DELTA_PAN = 20
MIN_DELTA_PAN = 2

# TILT / UP-DOWN

HOLD_Y = 30
FAR_Y = 58

KP_TILT_NEAR = 0.075
KP_TILT_FAR = 0.18

MAX_DELTA_TILT = 14
MIN_DELTA_TILT = 3

COMMAND_DELAY = 0.030


CENTER_HOLD_SECONDS = 1.25


ALPHA_X = 0.63
ALPHA_Y = 0.60

CMD_ALPHA_PAN = 0.70
CMD_ALPHA_TILT = 0.66

MAX_CMD_CHANGE_PAN = 6
MAX_CMD_CHANGE_TILT = 5


OSC_IGNORE_PAN = 5
OSC_IGNORE_TILT = 4


MIN_STABLE_DETECTIONS = 2
MAX_CENTER_JUMP = 90
HIGH_CONF_ALLOW_JUMP = 0.70

PRINT_COMMANDS = False

# GLOBAL STATE

smooth_x = None
smooth_y = None

last_pan_cmd = 0
last_tilt_cmd = 0

last_command_time = 0
last_status_time = 0
last_sent_move = False

stable_detection_count = 0

center_hold_until = 0.0

_ui_fps = 0.0
_ui_last_t = time.time()

# LOW LATENCY CAMERA READER

class LatestFrameReader:
    def __init__(self, url):
        self.url = url
        self.host = None
        self.port = 81
        self.path = "/stream"

        if "://" in url:
            netloc = url.split("://", 1)[1]
            if "/" in netloc:
                host_port, self.path = netloc.split("/", 1)
                self.path = "/" + self.path
            else:
                host_port = netloc
            if ":" in host_port:
                self.host, port_str = host_port.split(":", 1)
                self.port = int(port_str)
            else:
                self.host = host_port
                self.port = 80
        else:
            self.host = url

        self.capture_url = f"http://{self.host}:80/capture"
        self.frame = None
        self.lock = threading.Lock()
        self.running = False
        self.thread = None

    def start(self):
        self.running = True
        self.thread = threading.Thread(target=self._loop, daemon=True)
        self.thread.start()

    def _stream_socket(self):
        s = socket.socket(socket.AF_INET, socket.SOCK_STREAM)
        s.settimeout(3.0)
        s.connect((self.host, self.port))
        req = f"GET {self.path} HTTP/1.1\r\nHost: {self.host}:{self.port}\r\nUser-Agent: Mozilla/5.0\r\nAccept: */*\r\nConnection: close\r\n\r\n"
        s.sendall(req.encode())

        buffer = b""
        while self.running:
            chunk = s.recv(4096)
            if not chunk:
                break
            buffer += chunk
            a = buffer.find(b"\xff\xd8")
            b = buffer.find(b"\xff\xd9")
            if a != -1 and b != -1:
                if b > a:
                    jpg = buffer[a:b+2]
                    buffer = buffer[b+2:]
                    frame = cv2.imdecode(np.frombuffer(jpg, dtype=np.uint8), cv2.IMREAD_COLOR)
                    if frame is not None:
                        with self.lock:
                            self.frame = frame
                else:
                    buffer = buffer[a:]
        s.close()

    def _loop(self):
        while self.running:
            try:
                self._stream_socket()
            except Exception:
                # Fallback to /capture endpoint if streaming port is busy
                try:
                    req = urllib.request.Request(self.capture_url, headers={"User-Agent": "Mozilla/5.0"})
                    with urllib.request.urlopen(req, timeout=1.5) as resp:
                        arr = np.frombuffer(resp.read(), dtype=np.uint8)
                        frame = cv2.imdecode(arr, cv2.IMREAD_COLOR)
                        if frame is not None:
                            with self.lock:
                                self.frame = frame
                except Exception:
                    time.sleep(0.05)
            time.sleep(0.005)

    def read(self):
        with self.lock:
            if self.frame is None:
                return None
            return self.frame.copy()

    def stop(self):
        self.running = False
        if self.thread is not None:
            self.thread.join(timeout=1.0)

# FUNCTIONS

def clamp(value, min_value, max_value):
    return max(min_value, min(max_value, value))


def sign_of(value):
    if value > 0:
        return 1
    if value < 0:
        return -1
    return 0


def limit_change(new_value, old_value, max_change):
    diff = new_value - old_value

    if diff > max_change:
        return old_value + max_change

    if diff < -max_change:
        return old_value - max_change

    return new_value


def anti_oscillation(new_cmd, old_cmd, ignore_threshold):
    if new_cmd == 0:
        return 0

    if old_cmd == 0:
        return new_cmd

    if sign_of(new_cmd) != sign_of(old_cmd) and abs(new_cmd) <= ignore_threshold:
        return 0

    return new_cmd
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
